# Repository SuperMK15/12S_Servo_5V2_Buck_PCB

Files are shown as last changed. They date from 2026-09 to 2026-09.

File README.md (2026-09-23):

# 12S to Servo 5V2 Buck PCB

Custom Battery Eliminator Circuit (BEC) PCB built around the **LM65680RZYR** buck switching regulator IC, efficiently stepping down a 12S battery input (36V–50.4V) to 5.2V and supporting up to 8A of continuous draw for VTOL drone servo rails.

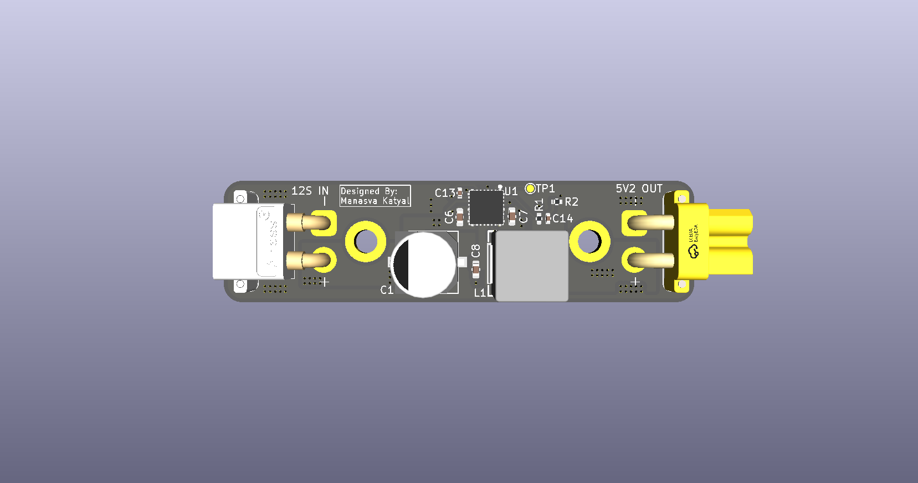
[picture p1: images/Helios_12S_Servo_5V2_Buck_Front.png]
Front View

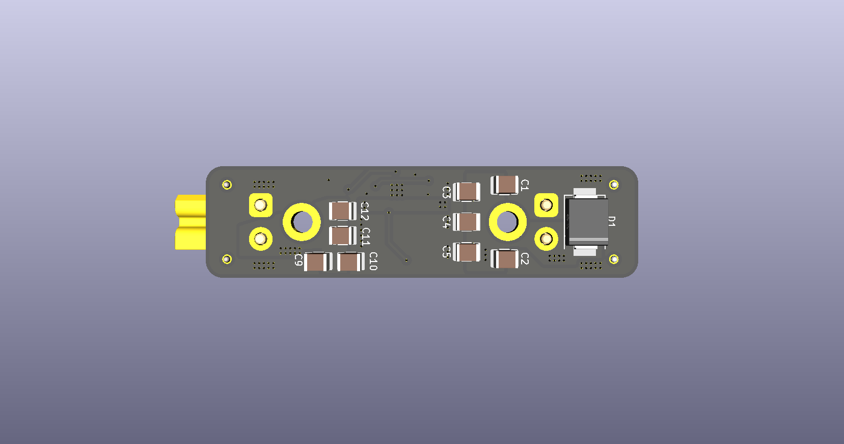
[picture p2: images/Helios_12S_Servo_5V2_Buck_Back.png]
Back View


## Features

* Built around the LM65680RZYR buck switching regulator IC.
* 12S battery input supporting 36V to 50.4V via an XT30 male connector.
* 5.2V output supporting up to 8A maximum draw via an XT30 female connector.
* Input overvoltage protection utilizing an SMCJ54A TVS diode.
* Dedicated test point for Power Good (PG) monitoring.
* Two mounting holes, following a standard 30.5 × 30.5 mm M3 mounting pattern.

## PCB Layers

### Front Copper (Layer 1)

Front Copper

### Ground (Layer 2)

Ground

### Ground (Layer 3)

5.2 V

### Back Copper (Layer 4)

Back Copper

## Design Files

Designed in **KiCad 10**. Includes the complete schematic, PCB layout, custom footprints/symbols, and manufacturing files.

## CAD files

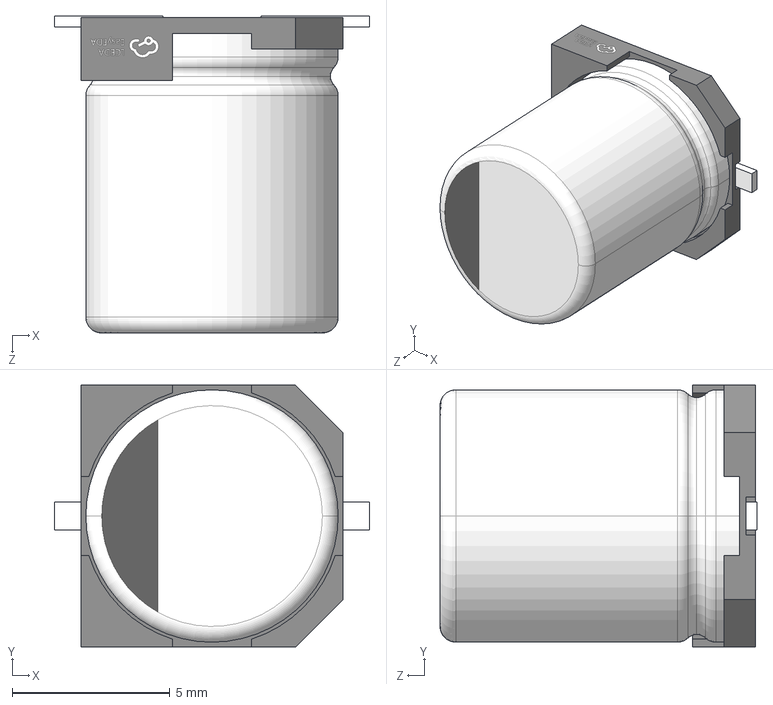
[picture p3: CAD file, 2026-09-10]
ul_EEETG2A220UP/CAP-SMD_BD8.0-L8.3-W8.3-FD.step
10.0 x 8.30 x 10.1 mm

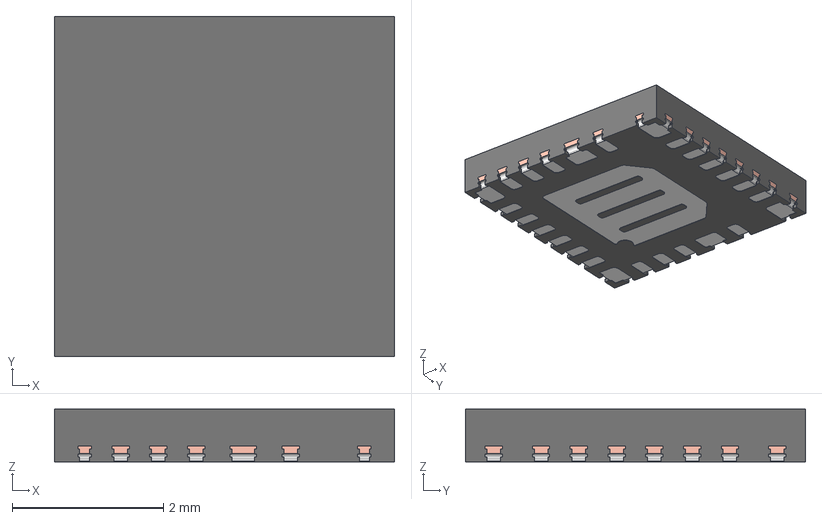
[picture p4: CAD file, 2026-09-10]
ul_LM65680RZYR/RZY0026A.stp
4.50 x 4.50 x 0.7 mm
RZY0026A_FRAME
RZY0026A_MOLD

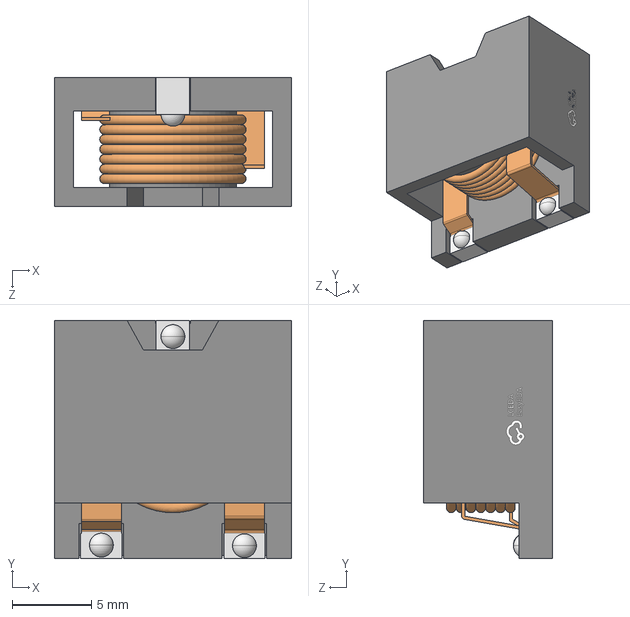
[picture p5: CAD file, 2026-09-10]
ul_MTM1480-3R9M-L/IND-SMD_3P-L14.9-W14.9.step
14.9 x 15.0 x 8.11 mm

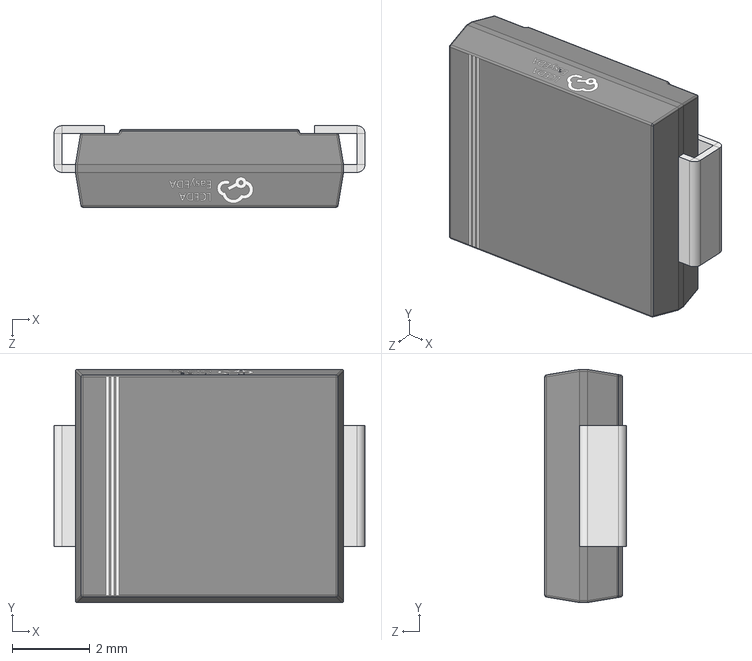
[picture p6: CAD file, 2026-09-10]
ul_SMCJ54A/SMC_L6.9-W5.9-LS7.9-RD.step
8.00 x 6.00 x 2.10 mm

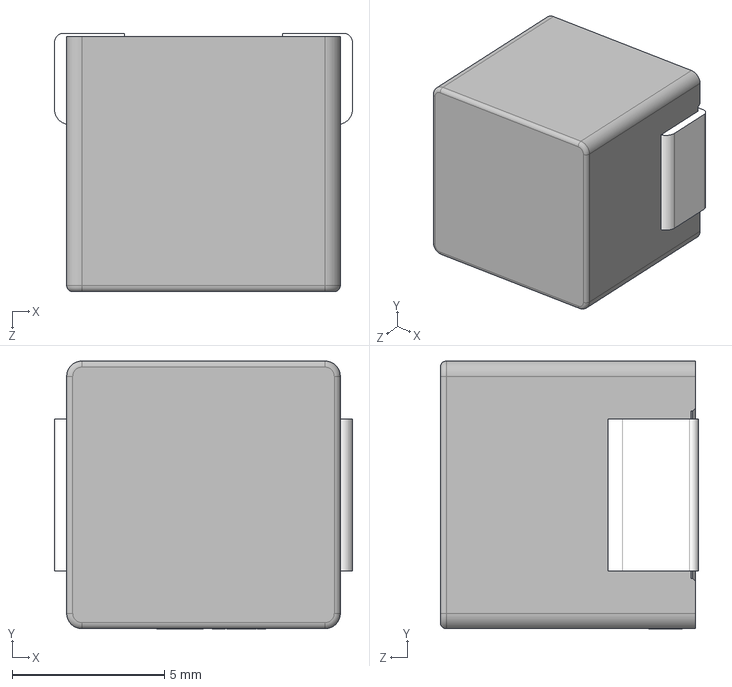
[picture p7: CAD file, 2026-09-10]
ul_SRYH.0885.YF4R7MT00/IND-SMD_L9.8-W8.8_SRYH.0885.YF.step
9.80 x 8.81 x 8.50 mm

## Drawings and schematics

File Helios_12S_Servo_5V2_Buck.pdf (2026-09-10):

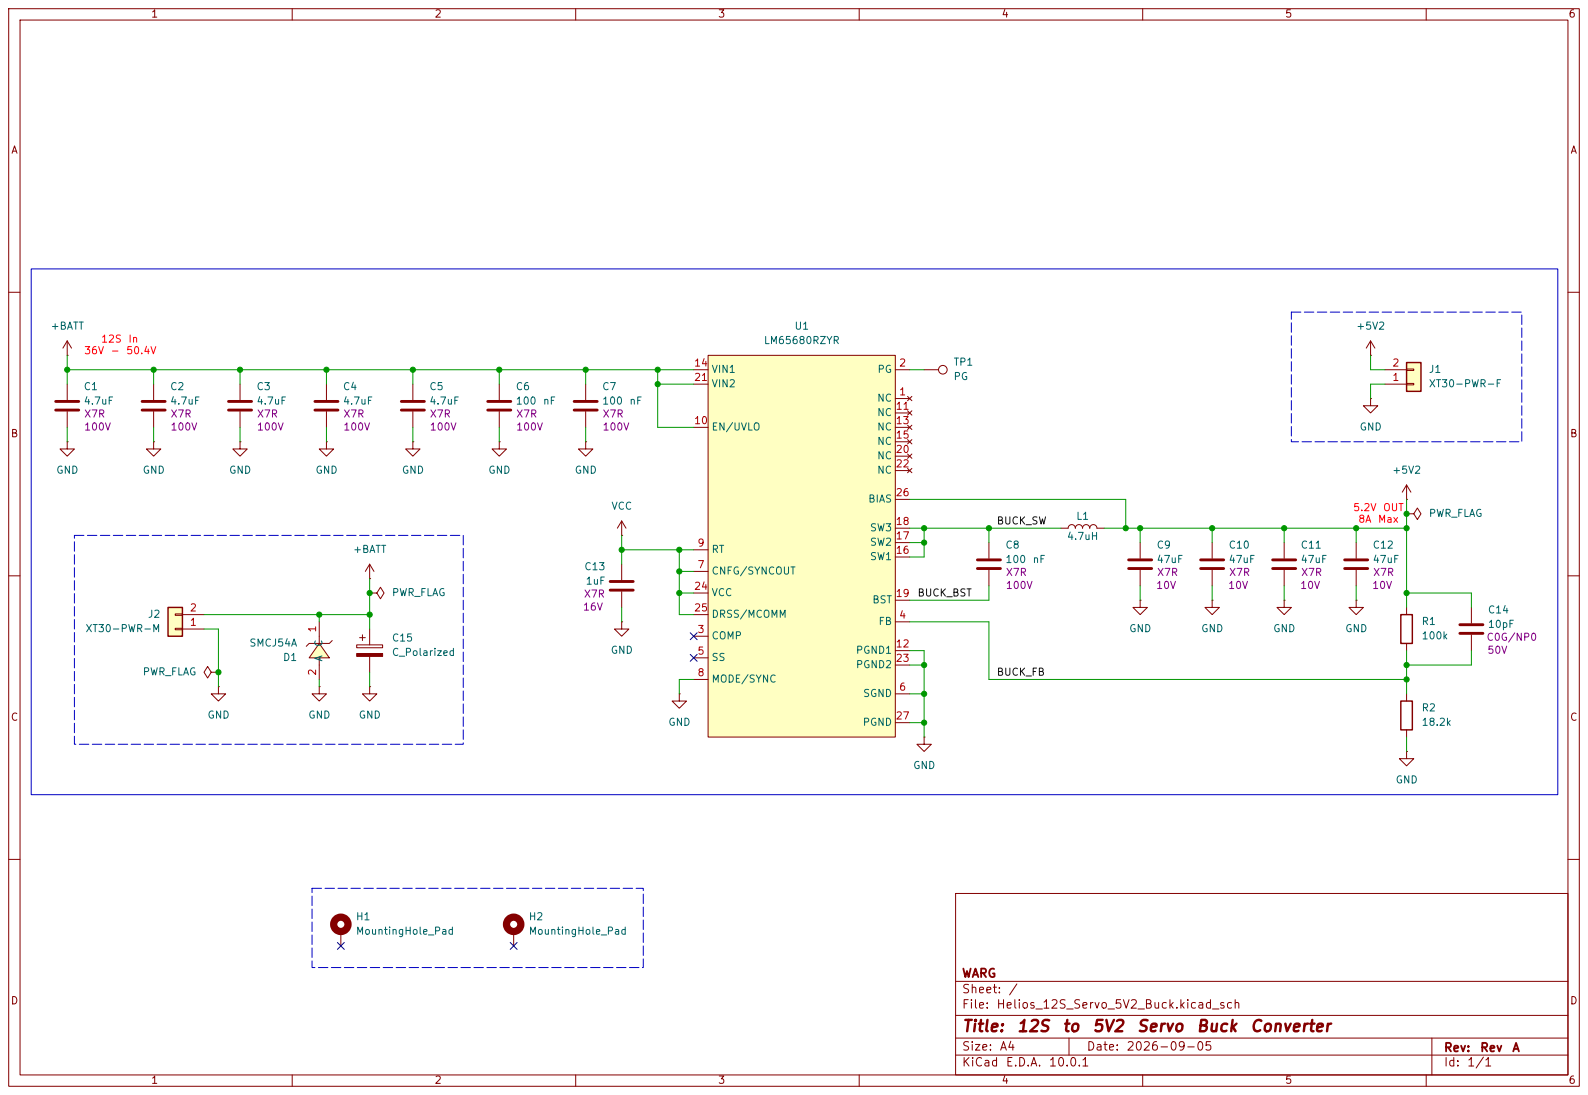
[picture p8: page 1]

WARG
Sheet: /
File: Helios_12S_Servo_5V2_Buck.kicad_sch
Title: 12S to 5V2 Servo Buck Converter

Size: A4 | Rev: Rev A
KiCad E.D.A. 10.0.1 | Id: 1/1

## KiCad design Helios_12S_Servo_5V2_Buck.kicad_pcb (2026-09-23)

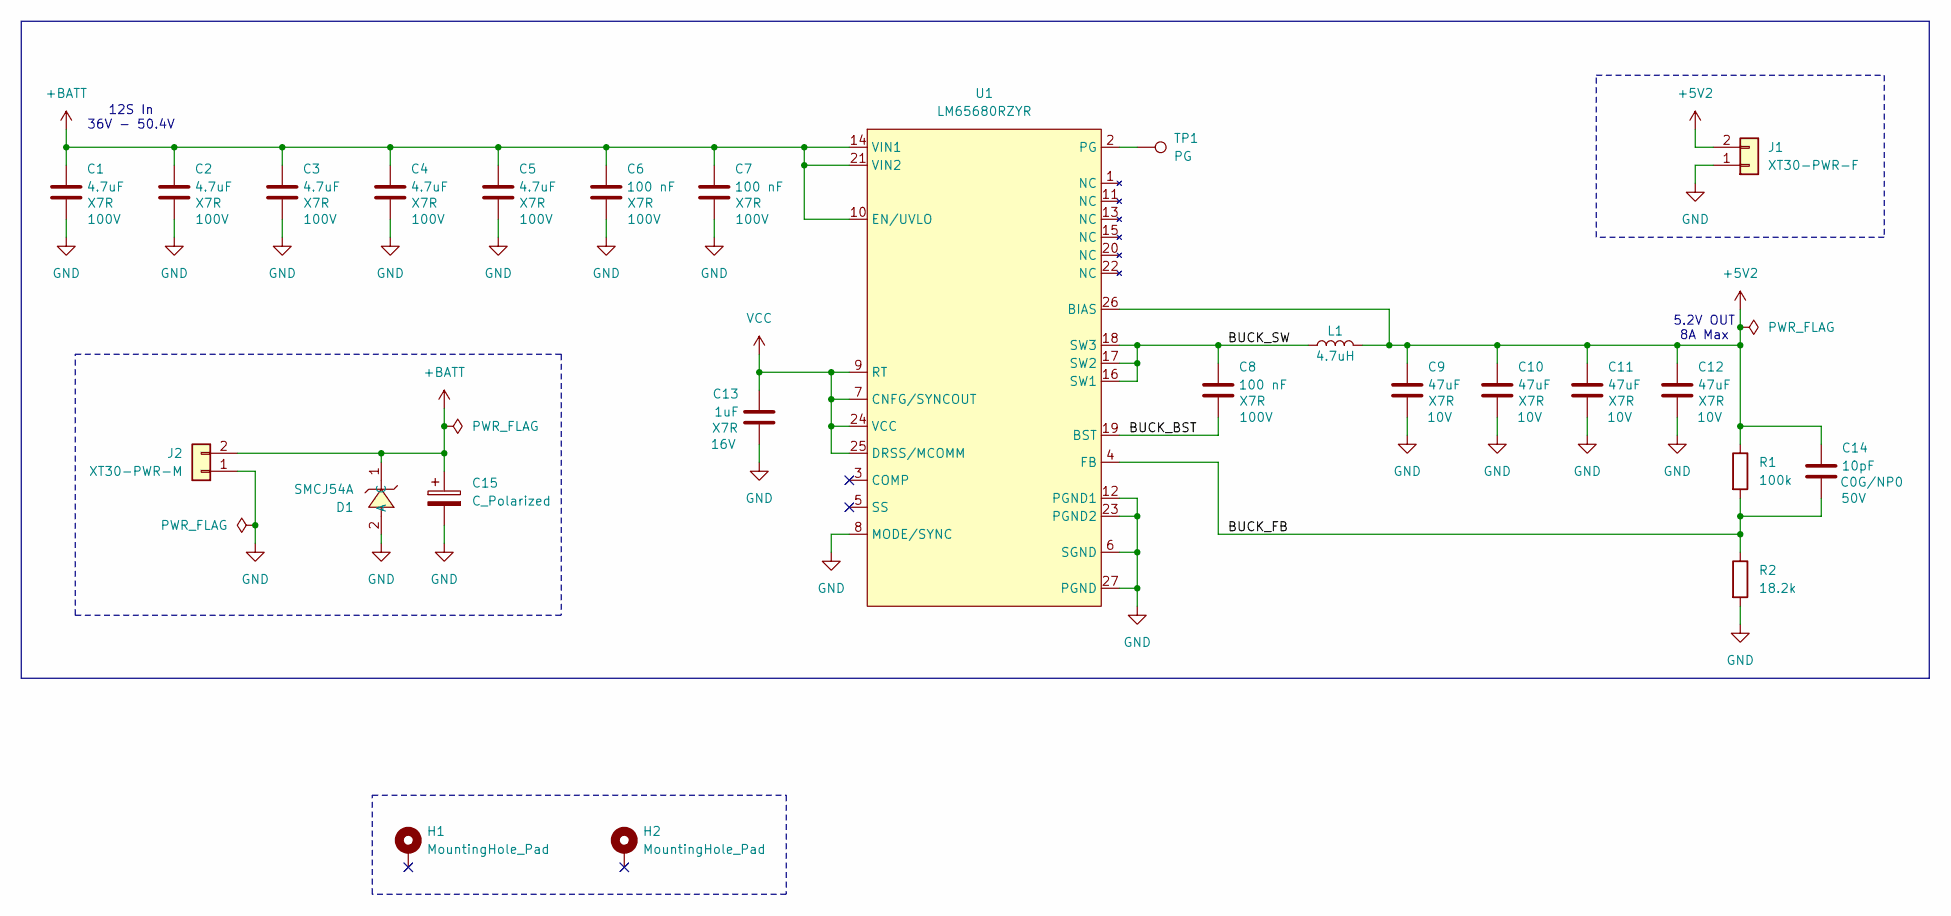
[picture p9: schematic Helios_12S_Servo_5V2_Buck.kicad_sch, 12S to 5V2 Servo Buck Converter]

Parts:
C1, C2, C3, C4, C5: 4.7uF; C_1210_3225Metric; Temp Rating X7R; LCSC C22877898
C6, C7, C8: 100 nF; C_0603_1608Metric; Temp Rating X7R; LCSC C15725
C9, C10, C11, C12: 47uF; C_1210_3225Metric; Temp Rating X7R; LCSC C84494
C13: 1uF; C_0402_1005Metric; Temp Rating X7R; LCSC C49210445
C14: 10pF; C_0402_1005Metric; Temp Rating C0G/NP0; LCSC C32949
C15: C_Polarized; CAP-SMD_BD8.0-L8.3-W8.3-FD; LCSC C401897
D1: SMCJ54A; SMC_L6.9-W5.9-LS7.9-RD; LCSC C720068
H1, H2: MountingHole_Pad; MountingHole_3.2mm_M3_DIN965_Pad
J1: XT30-PWR-F; AMASS_XT30PW-F_1x02_P2.50mm_Horizontal; LCSC C2913282
J2: XT30-PWR-M; AMASS_XT30PW-M_1x02_P2.50mm_Horizontal; LCSC C431092
L1: 4.7uH; IND-SMD_L9.8-W8.8_SRYH.0885.YF; LCSC C50325381
R1: 100k; R_0402_1005Metric; LCSC C25741
R2: 18.2k; R_0402_1005Metric; LCSC C2076827
TP1: PG; TestPoint_Pad_D1.0mm
U1: LM65680RZYR; VQFN-26_L4.5-W4.5-LM65660-Q1; LCSC C53201929

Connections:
+5V2: C9.1, C10.1, C11.1, C12.1, C14.1, J1.2, L1.2, R1.1, U1.26 (BIAS)
+BATT: C1.1, C2.1, C3.1, C4.1, C5.1, C6.1, C7.1, C15.1, D1.1 (C), J2.2, U1.10 (EN/UVLO), U1.14 (VIN1), U1.21 (VIN2)
/BUCK_BST: C8.2, U1.19 (BST)
/BUCK_FB: C14.2, R1.2, R2.1, U1.4 (FB)
/BUCK_SW: C8.1, L1.1, U1.16 (SW1), U1.17 (SW2), U1.18 (SW3)
GND: C1.2, C2.2, C3.2, C4.2, C5.2, C6.2, C7.2, C9.2, C10.2, C11.2, C12.2, C13.2, C15.2, D1.2 (A), J1.1, J2.1, R2.2, U1.6 (SGND), U1.8 (MODE/SYNC), U1.12 (PGND1), U1.23 (PGND2), U1.27 (PGND)
unnamed: TP1.1 (1_1), U1.2 (PG)
VCC: C13.1, U1.7 (CNFG/SYNCOUT), U1.9 (RT), U1.24 (VCC), U1.25 (DRSS/MCOMM)

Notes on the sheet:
5.2V OUT 8A Max
12S In 36V - 50.4V

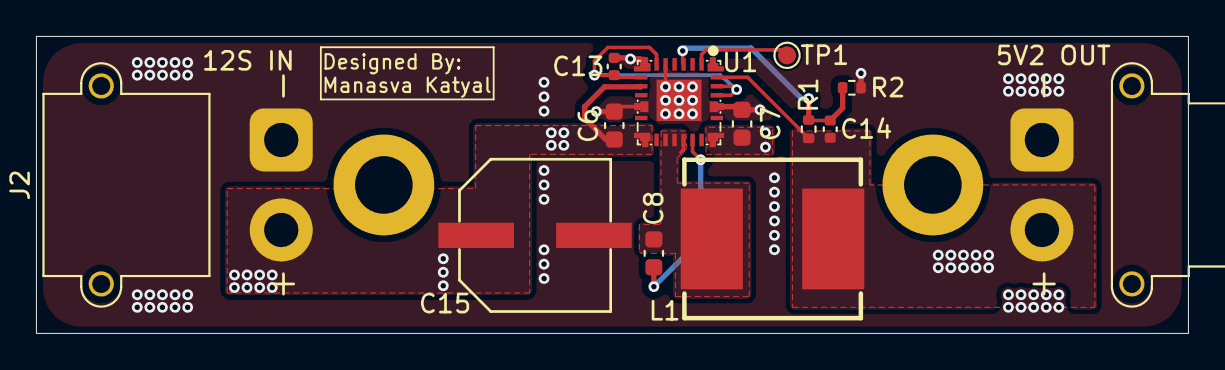
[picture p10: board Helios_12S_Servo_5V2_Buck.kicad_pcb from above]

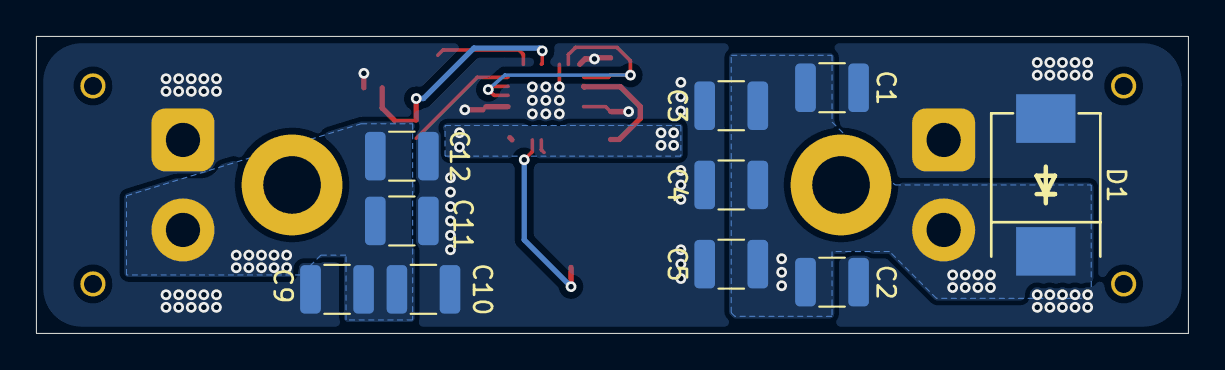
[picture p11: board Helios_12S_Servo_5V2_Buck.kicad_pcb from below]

Board: 4 copper layers, 64.0 x 16.5 mm, 25 parts (10 on the bottom side), 8 nets.

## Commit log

2026-09-10 Update README with PCB details and features
    Added detailed information about the Custom Battery Eliminator Circuit PCB, including features, PCB layers, and design files.
2026-09-21 Update layout/routing
    [Helios_12S_Servo_5V2_Buck.kicad_pcb]
2026-09-22 Update production files
    [Helios_12S_Servo_5V2_Buck.kicad_sch]
2026-09-23 Update layout/routing + production files
    [Helios_12S_Servo_5V2_Buck.kicad_pcb]
